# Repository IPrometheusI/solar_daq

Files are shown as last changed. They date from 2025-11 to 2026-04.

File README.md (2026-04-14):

# Sistema de Adquisición de Datos para Paneles Solares






## Resumen
Este proyecto implementa un sistema DAQ para dos paneles solares usando una Raspberry Pi 4. El sistema mide variables eléctricas y ambientales cada minuto, guarda archivos CSV diarios en la Pi y puede integrarse con InfluxDB, Grafana y Google Drive para monitoreo y respaldo.

## Sensores y Variables
- `2x INA228`: voltaje, corriente, potencia y energía de cada panel.
- `ADS1115 + Spektron 210`: irradiancia solar.
- `20x termistores NTC + 3x CD74HC4051`: temperatura en múltiples puntos del sistema.
- `DHT22`: temperatura y humedad ambiente.
- `Anemómetro`: velocidad del viento.
- `Veleta resistiva`: dirección del viento.
- `Pluviómetro`: precipitación acumulada.

## Flujo del Sistema
- Adquisición automática en horario operativo.
- Escritura de CSV diarios en `/home/pi/Desktop/Mediciones/`.
- Monitoreo local desde terminal y panel de control.
- Integración opcional con InfluxDB/Grafana y sincronización con Google Drive.

## Vista del Proyecto
| Hardware | Terminal de adquisición |
| --- | --- |
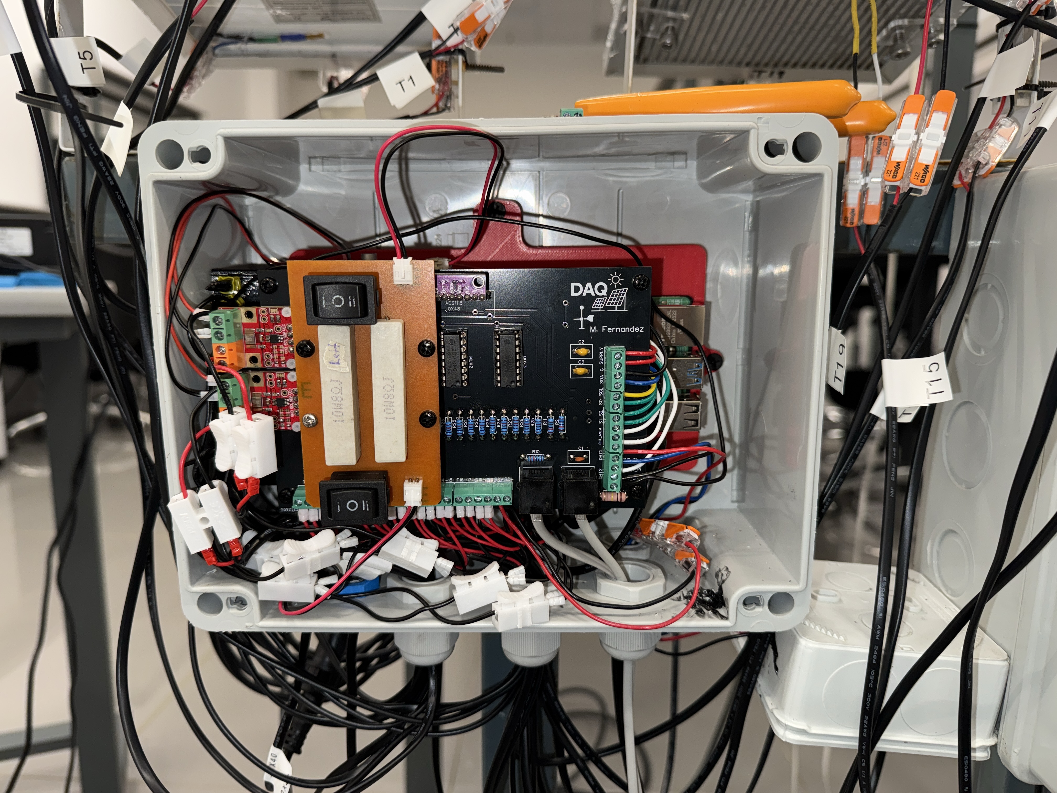
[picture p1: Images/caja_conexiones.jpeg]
Caja de conexiones del sistema
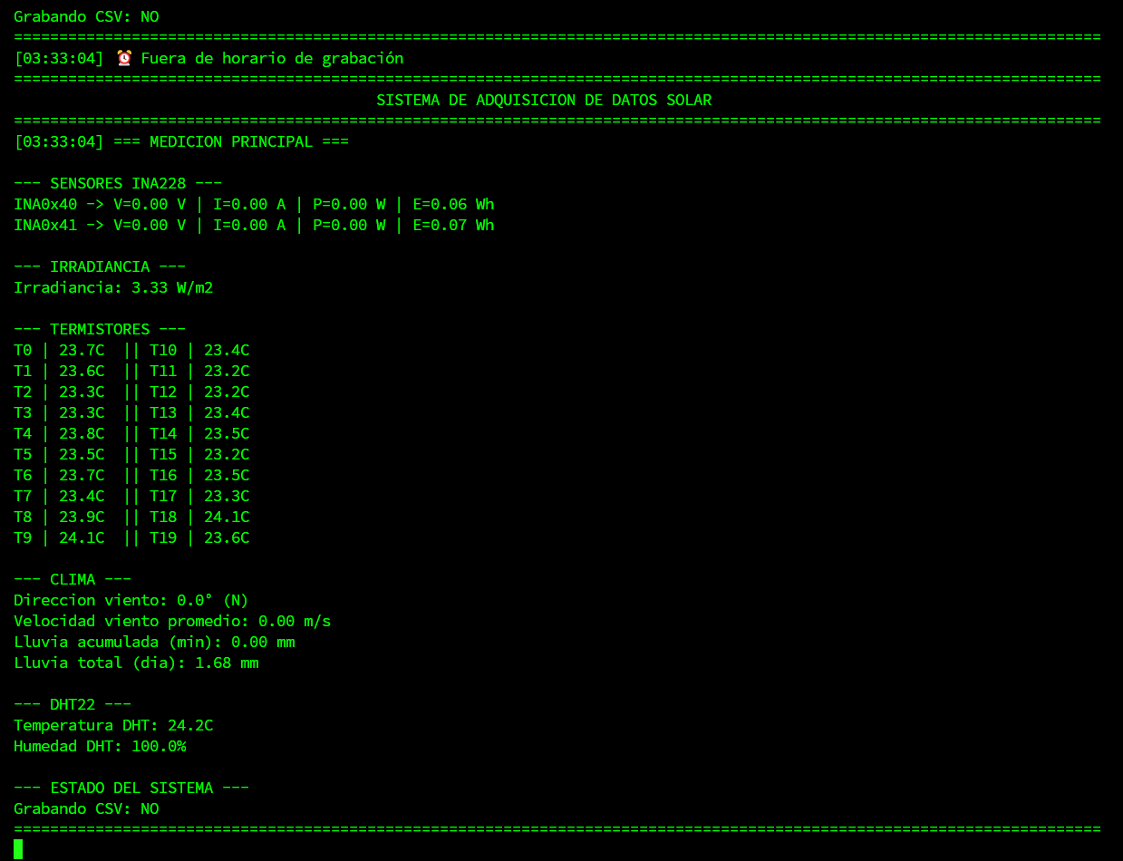
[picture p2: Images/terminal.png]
Salida en terminal del sistema DAQ
|  |  |

| Panel de control | Dashboard Grafana |
| --- | --- |
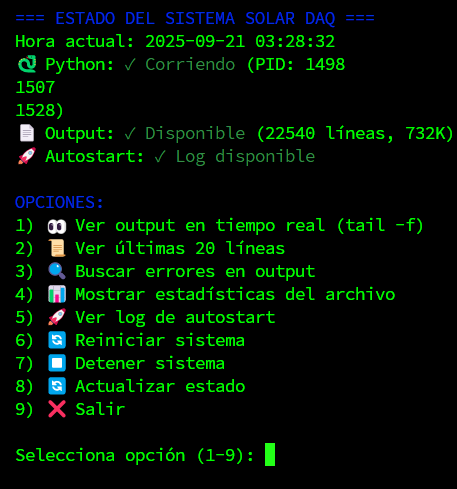
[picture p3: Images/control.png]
Panel de control en terminal
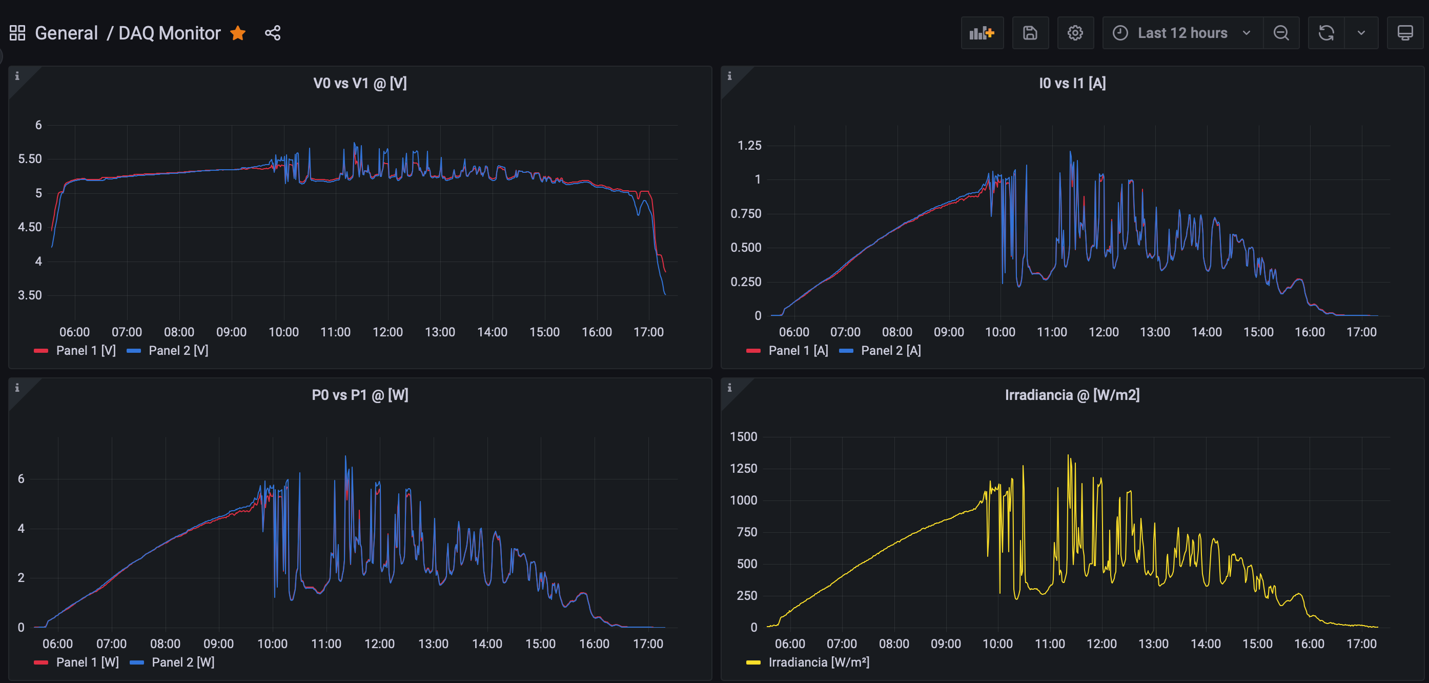
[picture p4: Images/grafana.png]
Dashboard en Grafana
|  |  |

### Respaldo en la nube
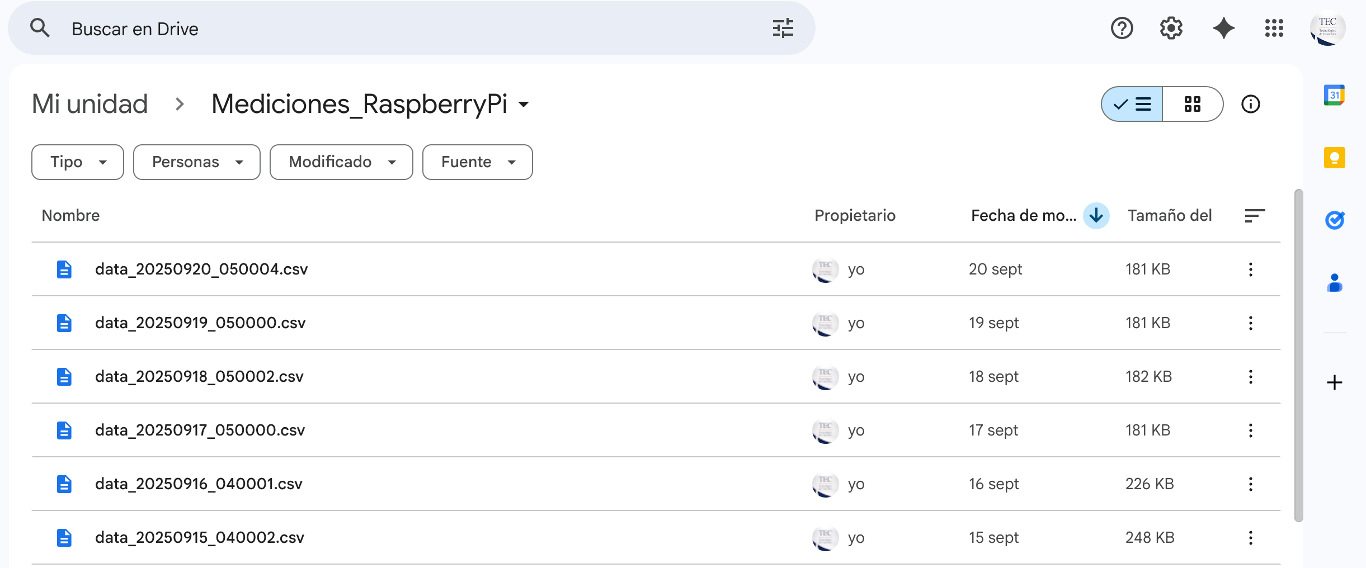
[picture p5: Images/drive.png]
Archivos CSV sincronizados en Google Drive


## Instalación en Raspberry Pi 4
Asumiendo que el hardware ya está correctamente conectado y que la Raspberry Pi OS ya está lista:

```bash
cd /home/pi/Desktop
git clone https://github.com/IPrometheusI/solar_daq.git
cd solar_daq
sudo bash setup_repo.sh
systemctl status solar_daq.service
```

`setup_repo.sh` crea el entorno virtual `.venv`, instala `requirements.txt`, copia los scripts de `bashScripts/` a `/home/pi/` y registra el servicio `solar_daq.service` para arranque automático.

Si vas a usar InfluxDB, usa [`.env.example`](.env.example) como plantilla:

```bash
cp .env.example .env
nano .env
```

Completa `INFLUX_URL`, `INFLUX_TOKEN`, `INFLUX_ORG` e `INFLUX_BUCKET`, y luego usa esos valores en el entorno donde correrá el servicio. No subas `.env` al repositorio.

## Operación Rápida
```bash
sudo systemctl start solar_daq.service
sudo systemctl stop solar_daq.service
/home/pi/control_solar_daq.sh
tail -f /home/pi/solar_daq.log
```

## Cómo Citar
Si utilizas este software en tu investigación o proyecto, usa el DOI:

`10.5281/zenodo.19562081`

También puedes usar el archivo `CITATION.cff` incluido en el repositorio.

## Licencia
Este proyecto está licenciado bajo la **Licencia MIT**. Consulta [LICENSE](LICENSE) para más detalles.

Copyright (c) 2025 Maickol A. Fernandez Obando

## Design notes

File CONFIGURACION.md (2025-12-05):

# Configuración del Sistema

Este documento explica cómo configurar las credenciales de InfluxDB para el sistema de adquisición de datos solar.

## ⚠️ Importante - Seguridad

**NUNCA** subas archivos con credenciales reales a repositorios públicos. Las credenciales deben configurarse mediante variables de entorno o archivos `.env` locales.

---

## Método 1: Variables de entorno (Recomendado para producción)

### En Linux/macOS (Raspberry Pi)

1. **Edita el archivo de perfil de tu shell:**

   ```bash
   nano ~/.bashrc
   # o si usas zsh:
   nano ~/.zshrc
   ```

2. **Agrega al final del archivo:**

   ```bash
   # InfluxDB Configuration
   export INFLUX_URL="http://tu-servidor-influxdb.com"
   export INFLUX_TOKEN="tu-token-de-influxdb-aqui"
   export INFLUX_ORG="tu-organizacion"
   export INFLUX_BUCKET="tu-bucket"
   ```

3. **Recarga el archivo de configuración:**

   ```bash
   source ~/.bashrc
   # o si usas zsh:
   source ~/.zshrc
   ```

4. **Verifica que las variables estén configuradas:**

   ```bash
   echo $INFLUX_URL
   echo $INFLUX_TOKEN
   ```

### En Windows (PowerShell)

1. **Configura las variables de entorno del sistema:**

   ```powershell
   [System.Environment]::SetEnvironmentVariable('INFLUX_URL', 'http://tu-servidor-influxdb.com', 'User')
   [System.Environment]::SetEnvironmentVariable('INFLUX_TOKEN', 'tu-token-de-influxdb-aqui', 'User')
   [System.Environment]::SetEnvironmentVariable('INFLUX_ORG', 'tu-organizacion', 'User')
   [System.Environment]::SetEnvironmentVariable('INFLUX_BUCKET', 'tu-bucket', 'User')
   ```

2. **Reinicia PowerShell** para que las variables tomen efecto.

---

## Método 2: Archivo .env (Para desarrollo local)

1. **Copia el archivo de ejemplo:**

   ```bash
   cp .env.example .env
   ```

2. **Edita el archivo `.env` con tus credenciales:**

   ```bash
   nano .env
   ```

   ```env
   # InfluxDB Configuration
   INFLUX_URL=http://tu-servidor-influxdb.com
   INFLUX_TOKEN=tu-token-de-influxdb-aqui
   INFLUX_ORG=tu-organizacion
   INFLUX_BUCKET=tu-bucket
   ```

3. **Instala python-dotenv (si no está instalado):**

   ```bash
   pip install python-dotenv
   ```

4. **Modifica los scripts para cargar el archivo `.env`** (solo necesario si usas este método):

   Al inicio de cada script Python, agrega:

   ```python
   from dotenv import load_dotenv
   load_dotenv()  # Carga variables de .env
   ```

**Nota**: El archivo `.env` ya está en `.gitignore` y NO será subido al repositorio.

---

## Método 3: Editar directamente en el código (NO recomendado)

Solo para pruebas locales. **NO subir al repositorio con credenciales reales.**

Edita los valores directos en los archivos:

- `source/influxdb_sender.py`
- `InfluxService/delete_influx_range.py`
- `InfluxService/upload_csv_to_influx.py`

```python
INFLUX_CONFIG = {
    "url": "http://tu-servidor-influxdb.com",
    "token": "tu-token-de-influxdb-aqui",
    "org": "tu-organizacion",
    "bucket": "tu-bucket",
}
```

---

## Cómo obtener las credenciales de InfluxDB

### 1. URL del servidor

Es la dirección donde está alojado tu servidor InfluxDB.

**Ejemplo**: `http://influx.ejemplo.com` o `http://192.168.1.100:8086`

### 2. Token de acceso

1. Accede a la interfaz web de InfluxDB
2. Ve a **Data** → **API Tokens** (o **Load Data** → **Tokens**)
3. Copia un token existente o crea uno nuevo con los permisos necesarios:
   - **Read** access al bucket (para queries)
   - **Write** access al bucket (para escribir datos)
   - **Delete** access al bucket (para eliminar datos)

### 3. Organización (Org)

El nombre de tu organización en InfluxDB.

Puedes verlo en la interfaz web, generalmente en la esquina superior izquierda.

### 4. Bucket

El nombre del bucket (base de datos) donde se almacenan los datos.

Puedes verlo en **Data** → **Buckets** en la interfaz web de InfluxDB.

---

## Verificar la configuración

### Para el sistema principal (implementacion.py)

1. **Ejecuta el sistema:**

   ```bash
   cd source
   python implementacion.py
   ```

2. **Verifica el log de inicio**. Deberías ver:

   ```
   ✓ Conexión a InfluxDB establecida
   ```

   Si ves errores de conexión, verifica tus credenciales.

### Para los scripts de InfluxService

1. **Prueba la conexión:**

   ```bash
   cd InfluxService
   python upload_csv_to_influx.py
   ```

2. **Deberías ver:**

   ```
   Conectando a InfluxDB: http://tu-servidor...
   ✓ Conectado a InfluxDB
   ```

---

## Troubleshooting

### Error: "INFLUX_TOKEN environment variable not set"

**Solución**: Asegúrate de haber configurado las variables de entorno correctamente.

Verifica con:
```bash
echo $INFLUX_TOKEN
```

### Error: "Connection refused" o "Timeout"

**Posibles causas**:
- URL incorrecta
- Servidor InfluxDB no está corriendo
- Firewall bloqueando la conexión
- Problemas de red

**Solución**: Verifica la conectividad:
```bash
ping tu-servidor-influxdb.com
curl http://tu-servidor-influxdb.com/health
```

### Error: "Unauthorized" o "Invalid token"

**Posibles causas**:
- Token incorrecto
- Token expirado
- Permisos insuficientes

**Solución**: Verifica/regenera el token en la interfaz web de InfluxDB.

### Error: "Bucket not found"

**Posibles causas**:
- Nombre del bucket incorrecto
- Bucket no existe en la organización especificada

**Solución**: Verifica el nombre del bucket en InfluxDB UI.

---

## Configuración para inicio automático (Raspberry Pi)

Si quieres que el sistema inicie automáticamente con las variables de entorno:

### Usando systemd (Recomendado)

1. **Crea un archivo de servicio:**

   ```bash
   sudo nano /etc/systemd/system/solar-daq.service
   ```

2. **Contenido del archivo:**

   ```ini
   [Unit]
   Description=Solar DAQ System
   After=network.target

   [Service]
   Type=simple
   User=pi
   WorkingDirectory=/home/pi/solar_daq/source
   Environment="INFLUX_URL=http://tu-servidor-influxdb.com"
   Environment="INFLUX_TOKEN=tu-token-aqui"
   Environment="INFLUX_ORG=tu-organizacion"
   Environment="INFLUX_BUCKET=tu-bucket"
   ExecStart=/usr/bin/python3 /home/pi/solar_daq/source/implementacion.py
   Restart=always
   RestartSec=10

   [Install]
   WantedBy=multi-user.target
   ```

3. **Habilita e inicia el servicio:**

   ```bash
   sudo systemctl daemon-reload
   sudo systemctl enable solar-daq.service
   sudo systemctl start solar-daq.service
   ```

4. **Verifica el estado:**

   ```bash
   sudo systemctl status solar-daq.service
   ```

---

## Archivos que contienen configuración de InfluxDB

Los siguientes archivos necesitan las credenciales configuradas:

1. ✅ `source/influxdb_sender.py` - Sistema principal de envío en tiempo real
2. ✅ `InfluxService/upload_csv_to_influx.py` - Subir datos históricos
3. ✅ `InfluxService/delete_influx_range.py` - Eliminar datos

Todos usan las mismas variables de entorno, por lo que solo necesitas configurarlas una vez.

---

## Seguridad - Lista de verificación

- [ ] Las credenciales están en variables de entorno o archivo `.env`
- [ ] El archivo `.env` NO está en el repositorio git
- [ ] El archivo `.env` está en `.gitignore`
- [ ] No hay tokens hardcodeados en archivos Python
- [ ] Los tokens tienen solo los permisos necesarios
- [ ] Las credenciales se guardan de forma segura (no en texto plano en lugares públicos)

---

**Última actualización**: 2025-12-04

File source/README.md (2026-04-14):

# source

Esta carpeta contiene el runtime principal del sistema DAQ. Aqui vive el proceso que `setup_repo.sh` instala y que `start_solar_daq.sh` ejecuta mediante `systemd`.

## Archivos

- `implementacion.py`: bucle principal de adquisicion. Lee INA228, ADS1115, DHT22, anemometro, pluviometro e irradiancia; guarda CSV diarios y recupera estado despues de reinicios.
- `influxdb_sender.py`: integracion opcional con InfluxDB. Inicializa la conexion, genera puntos y reintenta si la conexion falla.

## Flujo operativo

1. `bashScripts/start_solar_daq.sh` activa `.venv`.
2. Ejecuta `source/implementacion.py`.
3. El sistema escribe CSV en `/home/pi/Desktop/Mediciones`.
4. El estado de recuperacion se guarda en `/home/pi/Desktop/sensor_system_state.json` y `/home/pi/Desktop/sensor_system_state_backup.json`.

## Configuracion relevante

- Horario operativo actual: `05:00` a `18:00`.
- Direcciones INA228 esperadas: `0x40` y `0x41`.
- ADS1115 esperado en `0x48`.
- InfluxDB usa `INFLUX_URL`, `INFLUX_TOKEN`, `INFLUX_ORG` e `INFLUX_BUCKET`.

## Ejecucion manual

```bash
source .venv/bin/activate
python source/implementacion.py
```

En Raspberry Pi, `pigpiod` debe estar activo antes de iniciar el sistema:

```bash
sudo systemctl enable --now pigpiod
```

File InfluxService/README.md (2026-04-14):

# InfluxService

Herramientas de utilidad para gestionar datos en InfluxDB del sistema de adquisición de datos solar.

## Descripción

Esta carpeta contiene scripts de Python para realizar operaciones de mantenimiento y recuperación de datos en la base de datos InfluxDB:

- **Subir datos históricos desde archivos CSV**
- **Eliminar datos en rangos de tiempo específicos**

Ambos scripts están diseñados para trabajar con la zona horaria de Costa Rica (`America/Costa_Rica`) y convertir automáticamente a UTC para InfluxDB.

---

## Archivos

### 1. `upload_csv_to_influx.py`

**Propósito**: Subir datos históricos desde archivos CSV a InfluxDB con filtrado por rango de tiempo.

**Uso típico**:
- Recuperar datos perdidos por problemas de conectividad
- Migrar datos históricos a InfluxDB
- Re-subir datos específicos de ciertos períodos

#### Características

- ✅ Lectura automática de archivos CSV desde `archivos_csv/`
- ✅ Filtrado por rango de tiempo (hora inicio - hora fin)
- ✅ Conversión automática de timezone CR → UTC
- ✅ Manejo de BOM UTF-8
- ✅ Mapeo completo de todos los campos del CSV a InfluxDB
- ✅ Validación de datos antes de subir
- ✅ Contador de puntos subidos y omitidos

#### Formato de archivos CSV esperado

```
data_YYYYMMDD_HHMMSS.csv
```

Ejemplo: `data_20251018_083000.csv`

#### Estructura del CSV

El CSV debe contener las siguientes columnas:

**Columnas principales:**
- `V0[V]`, `V1[V]` - Voltaje paneles 1 y 2
- `I0[A]`, `I1[A]` - Corriente paneles 1 y 2
- `P0[W]`, `P1[W]` - Potencia paneles 1 y 2
- `E0[Wh]`, `E1[Wh]` - Energía acumulada paneles 1 y 2
- `Irr[W/m2]` - Irradiancia
- `Rain[mm]` - Lluvia acumulada
- `Wind_Speed[m/s]` - Velocidad del viento
- `Wind_Direction` - Dirección del viento (formato: `90.0°(E)`)
- `DHT_HUM[%]` - Humedad ambiente
- `DHT_TEMP[°C]` - Temperatura ambiente

**Termistores:**
- `T0[°C]` a `T19[°C]` - 20 sensores de temperatura

**Timestamp:**
- `DateTime` - Formato: `YYYY-MM-DD HH:MM:SS` (hora local CR)

#### Mapeo a InfluxDB

| Columna CSV | Field InfluxDB | Tipo |
|---|---|---|
| V0[V] | panel1_voltage | float |
| V1[V] | panel2_voltage | float |
| I0[A] | panel1_current | float |
| I1[A] | panel2_current | float |
| P0[W] | panel1_power | float |
| P1[W] | panel2_power | float |
| E0[Wh] | panel1_energy | float |
| E1[Wh] | panel2_energy | float |
| Irr[W/m2] | irradiance | float |
| Rain[mm] | rain_accumulation | float |
| Wind_Speed[m/s] | wind_speed | float |
| Wind_Direction | wind_direction | float (solo grados) |
| DHT_HUM[%] | ambient_humidity | float |
| DHT_TEMP[°C] | ambient_temperature | float |
| T0[°C] - T19[°C] | thermistor_00_temp - thermistor_19_temp | float |

**Tags adicionales:**
- `system`: `raspberry_pi`
- `location`: `solar_farm`

**Measurement**: `solar_panel_measurement`

#### Cómo usar

1. **Asegúrate de tener archivos CSV en la carpeta `archivos_csv/`**

2. **Ejecuta el script:**
   ```bash
   python upload_csv_to_influx.py
   ```

3. **Sigue las instrucciones interactivas:**
   ```
   === CSV to InfluxDB Uploader ===

   Archivos CSV disponibles:
     1. data_20251018_083000.csv - 2025-10-18 08:30:00
     2. data_20251019_083000.csv - 2025-10-19 08:30:00

   Seleccione el archivo CSV (1-2): 1

   Archivo seleccionado: data_20251018_083000.csv
   Fecha del archivo: 2025-10-18

   Ingrese el rango de tiempo para subir datos:
   Formato: HH:MM (ejemplo: 08:30)

   Hora inicio (HH:MM): 08:30
   Hora fin (HH:MM): 17:45

   Rango seleccionado: 08:30 - 17:45

   ¿Confirmar subida de datos a InfluxDB? (si/no): si
   ```

4. **El script mostrará el progreso:**
   ```
   Conectando a InfluxDB: http://tu-servidor-influxdb.com...
   ✓ Conectado a InfluxDB

   ✓ Uploaded 558 points from data_20251018_083000.csv
     Skipped 0 points outside time range

   === Resumen ===
   Archivo procesado: data_20251018_083000.csv
   Rango de tiempo: 08:30 - 17:45
   Puntos totales subidos: 558
   ✓ Carga completada exitosamente
   ```

#### Casos especiales

**Rangos que cruzan medianoche:**

El script maneja correctamente rangos de tiempo que cruzan la medianoche:

```
Hora inicio (HH:MM): 23:00
Hora fin (HH:MM): 02:00
```

Esto subirá datos desde las 23:00 hasta las 02:00 del día siguiente.

**Valores N/A o inválidos:**

El script omite automáticamente valores que son:
- Vacíos
- "N/A"
- NaN
- No numéricos

---

### 2. `delete_influx_range.py`

**Propósito**: Eliminar datos de InfluxDB en un rango de tiempo específico.

**Uso típico**:
- Eliminar datos corruptos o erróneos
- Limpiar datos de pruebas
- Corregir datos duplicados

#### Características

- ✅ Conversión automática de hora local CR a UTC
- ✅ Previsualización de puntos a eliminar antes de confirmar
- ✅ Confirmación explícita requerida (escribir "DELETE")
- ✅ Validación de formato de fecha y hora
- ✅ Soporte para filtrado por tags (opcional)

#### Cómo usar

1. **Ejecuta el script:**
   ```bash
   python delete_influx_range.py
   ```

2. **Sigue las instrucciones interactivas:**
   ```
   === Delete InfluxDB Data ===

   Ingrese los datos para eliminar:

   Fecha (YYYY-MM-DD, ejemplo: 2025-10-18): 2025-10-18
   Hora inicio (HH:MM, ejemplo: 08:30): 08:30
   Hora fin (HH:MM, ejemplo: 17:45): 17:45

   === Plan de Eliminación ===
    URL        : http://tu-servidor-influxdb.com
    Org        : tu-organizacion
    Bucket     : tu-bucket
    Measurement: solar_panel_measurement
    Tags       : (none)
    Local CR   : 2025-10-18 08:30 -> 17:45
    UTC Window : 2025-10-18T14:30:00Z -> 2025-10-18T23:45:00Z  (stop is exclusive)
    Predicate  : _measurement="solar_panel_measurement"
   ============================

   Puntos encontrados que coinciden: 558

   ¿Confirmar eliminación de estos datos? Escriba 'DELETE' para confirmar: DELETE

   ✅ Solicitud de eliminación completada exitosamente.
   ```

#### ⚠️ Advertencias importantes

1. **La eliminación es IRREVERSIBLE** - Los datos no se pueden recuperar después de eliminar
2. **Debes escribir exactamente "DELETE"** en mayúsculas para confirmar
3. **El tiempo de fin (stop) es EXCLUSIVO** - Los datos en ese momento exacto NO se eliminan
4. **Verifica siempre el preview** antes de confirmar

#### Funcionamiento técnico

El script utiliza la **InfluxDB Delete API** que tiene las siguientes limitaciones:

- ✅ Puede filtrar por `_measurement`
- ✅ Puede filtrar por tags
- ❌ **NO puede filtrar por fields** (_field)

Esto significa que eliminará **todos los fields** que coincidan con el measurement y tags en el rango de tiempo especificado.

---

## Requisitos

### Dependencias Python

Ambos scripts requieren las siguientes dependencias:

```bash
pip install influxdb-client
```

Para Python < 3.9, también necesitas:

```bash
pip install backports.zoneinfo
```

### Python versión

- **Recomendado**: Python 3.9 o superior (soporte nativo de zoneinfo)
- **Mínimo**: Python 3.7 (requiere backports.zoneinfo)

### Configuración de InfluxDB

Los scripts usan la siguiente configuración (definida en ambos archivos):

```python
INFLUX_CONFIG = {
    "url": "http://tu-servidor-influxdb.com",
    "token": "tu-token-de-influxdb-aqui",
    "org": "tu-organizacion",
    "bucket": "tu-bucket",
}
```

**Nota de seguridad**: En producción, considera mover el token a variables de entorno:

```python
import os
INFLUX_CONFIG = {
    "token": os.getenv("INFLUX_TOKEN"),
    # ...
}
```

---

## Zona Horaria

**Importante**: Ambos scripts trabajan con la zona horaria de **Costa Rica** (`America/Costa_Rica`).

- **Entrada del usuario**: Hora local de Costa Rica
- **Conversión automática**: Los scripts convierten a UTC para InfluxDB
- **UTC offset**: Costa Rica = UTC-6 (sin cambio de horario de verano)

### Ejemplo de conversión:

```
Local CR: 2025-10-18 08:30
UTC:      2025-10-18 14:30
```

---

## Estructura de directorios esperada

```
solar_daq/
├── InfluxService/
│   ├── README.md                    # Este archivo
│   ├── upload_csv_to_influx.py     # Subir CSVs
│   └── delete_influx_range.py      # Eliminar datos
├── archivos_csv/                    # Carpeta de CSVs (para upload)
│   ├── data_20251018_083000.csv
│   ├── data_20251019_083000.csv
│   └── ...
└── source/
    ├── implementacion.py            # Sistema principal
    └── influxdb_sender.py          # Envío en tiempo real
```

---

## Flujo de trabajo común

### Escenario 1: Recuperar datos perdidos

1. **Identifica el período sin datos** en InfluxDB
2. **Localiza el archivo CSV correspondiente** en `archivos_csv/`
3. **Ejecuta `upload_csv_to_influx.py`**
4. **Selecciona el archivo y rango de tiempo**
5. **Confirma la subida**

### Escenario 2: Corregir datos erróneos

1. **Identifica el rango de datos incorrectos**
2. **Ejecuta `delete_influx_range.py`**
3. **Especifica fecha y rango de tiempo**
4. **Verifica el preview de puntos a eliminar**
5. **Confirma con "DELETE"**
6. **Re-sube los datos correctos** con `upload_csv_to_influx.py`

### Escenario 3: Datos duplicados

1. **Identifica el rango duplicado**
2. **Ejecuta `delete_influx_range.py`** para eliminar todos los datos del rango
3. **Ejecuta `upload_csv_to_influx.py`** para re-subir los datos correctos una sola vez

---

## Troubleshooting

### Error: "Module 'zoneinfo' not found"

**Solución**:
```bash
pip install backports.zoneinfo
```

### Error: "Module 'influxdb_client' not found"

**Solución**:
```bash
pip install influxdb-client
```

### Error: "Folder 'archivos_csv' does not exist"

**Solución**: Crea la carpeta o ajusta la ruta en el script:
```bash
mkdir archivos_csv
```

O modifica la constante:
```python
CSV_FOLDER = "ruta/a/tus/csvs"
```

### InfluxDB health check failed

**Posibles causas**:
- Servidor InfluxDB no disponible
- Token inválido o expirado
- Problemas de red/firewall

**Solución**:
```bash
# Verifica conectividad
ping tu-servidor-influxdb.com

# Verifica el servidor InfluxDB está corriendo
curl http://tu-servidor-influxdb.com/health
```

### Puntos encontrados: 0 (pero debería haber datos)

**Posibles causas**:
- Rango de tiempo incorrecto
- Measurement name diferente
- Datos ya fueron eliminados

**Solución**: Verifica con una query Flux en InfluxDB UI:
```flux
from(bucket: "tu-bucket")
  |> range(start: -7d)
  |> filter(fn: (r) => r._measurement == "solar_panel_measurement")
  |> limit(n: 10)
```

---

## Advertencias de seguridad

⚠️ **Token de acceso**: Los scripts contienen el token de InfluxDB en texto plano. En producción:
- Usa variables de entorno
- Restringe permisos del archivo
- No subas el token a repositorios públicos

⚠️ **Permisos del token**: Asegúrate de que el token tiene:
- Permiso de **escritura** (write) para `upload_csv_to_influx.py`
- Permiso de **eliminación** (delete) para `delete_influx_range.py`
- Permiso de **lectura** (read) para preview queries

---

## Funciones documentadas

Cada función en los scripts está documentada siguiendo el formato:

```python
###################################
# nombre_funcion
# Argumentos:
#   - parametro1 (tipo): Descripción
#   - parametro2 (tipo): Descripción
# Return: tipo - Descripción del valor de retorno
# Descripcion: Descripción detallada de la función
###################################
```

Para más detalles, consulta directamente los archivos de código fuente.

---

## Contacto y soporte

Para problemas o preguntas sobre estos scripts, contacta al equipo de desarrollo del sistema de adquisición de datos solar.

---

**Última actualización**: 2025-12-04

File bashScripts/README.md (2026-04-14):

# bashScripts

Esta carpeta contiene los scripts auxiliares usados para arrancar, controlar y sincronizar el sistema Solar DAQ en la Raspberry Pi.

## Flujo actual
El arranque principal del sistema se hace con `start_solar_daq.sh`. Después de ejecutar `setup_repo.sh`, los scripts de esta carpeta se copian a `/home/pi/` y el servicio `solar_daq.service` usa `/home/pi/start_solar_daq.sh` para iniciar el software automáticamente al encender o reiniciar la Pi.

## Scripts

### `start_solar_daq.sh`
Lanzador principal del sistema.

- Resuelve la ruta real del repositorio.
- Activa el entorno virtual.
- Entra a `source/`.
- Ejecuta `implementacion.py`.
- Escribe eventos en `/home/pi/solar_daq.log`.

Uso manual:

```bash
/home/pi/start_solar_daq.sh
```

### `control_solar_daq.sh`
Panel de control en terminal, pensado para uso remoto por SSH o desde consola local.

Permite:
- ver `tail -f` del log
- revisar últimas líneas y errores
- iniciar, reiniciar o detener el sistema
- consultar estado general

Uso:

```bash
/home/pi/control_solar_daq.sh
```

### `sync_mediciones.sh`
Sincroniza los CSV de `/home/pi/Desktop/Mediciones` hacia Google Drive usando `rclone`.

Asume este remoto:

```bash
gdrive:Mediciones_RaspberryPi
```

Uso:

```bash
/home/pi/sync_mediciones.sh
```

Si quieres automatizar la sincronización, agrega una tarea en `crontab`:

```bash
crontab -e
```

Ejemplo, cada 5 minutos:

```cron
*/5 * * * * /home/pi/sync_mediciones.sh
```

### `resolve_project_root.sh`
Helper interno para encontrar la ruta real del repositorio aunque los scripts hayan sido copiados a `/home/pi`. No está pensado para ejecutarse directamente.

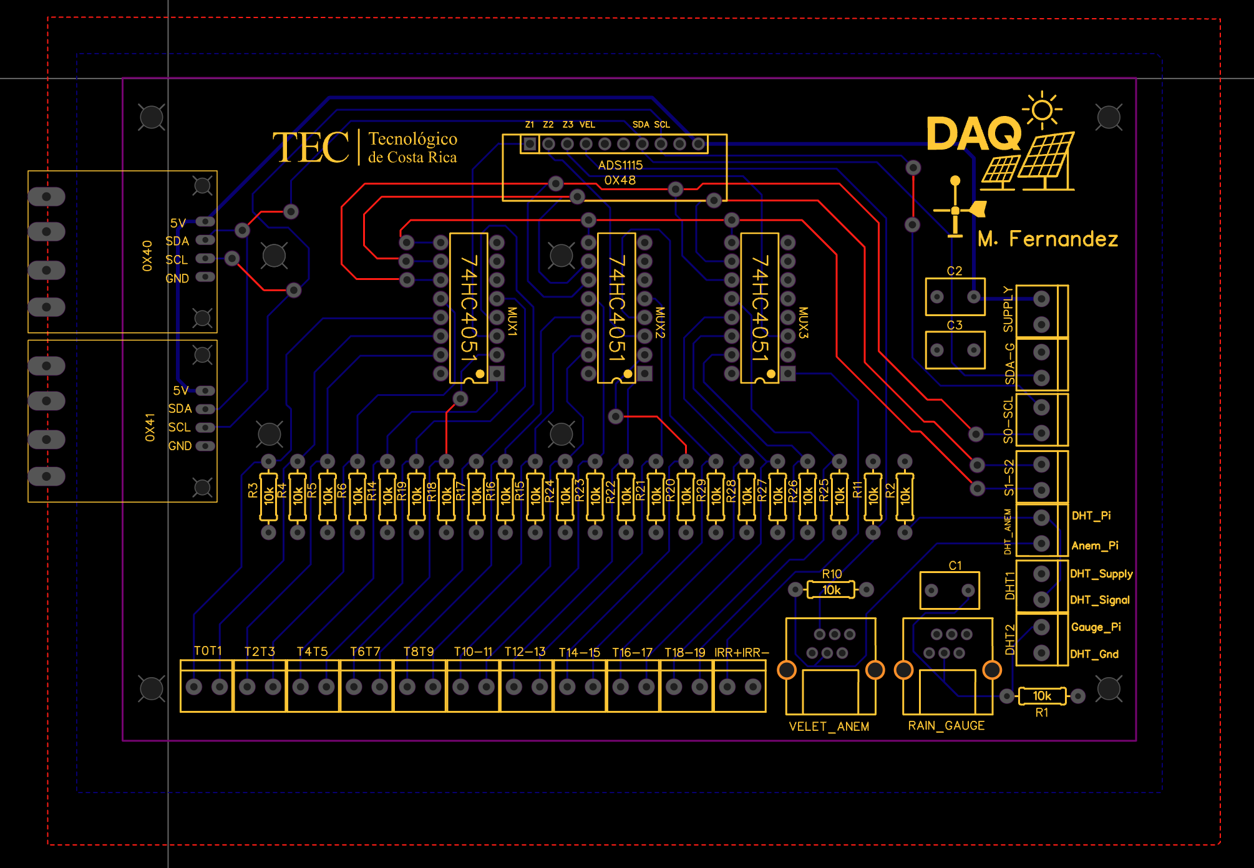
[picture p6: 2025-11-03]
Documentacion/Esquematicos/pcb_daq.png

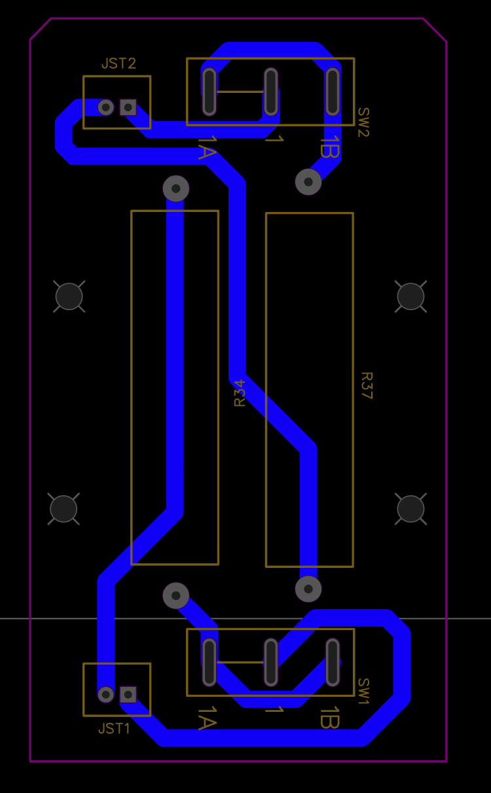
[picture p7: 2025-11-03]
Documentacion/Esquematicos/pcb_resistencias.png

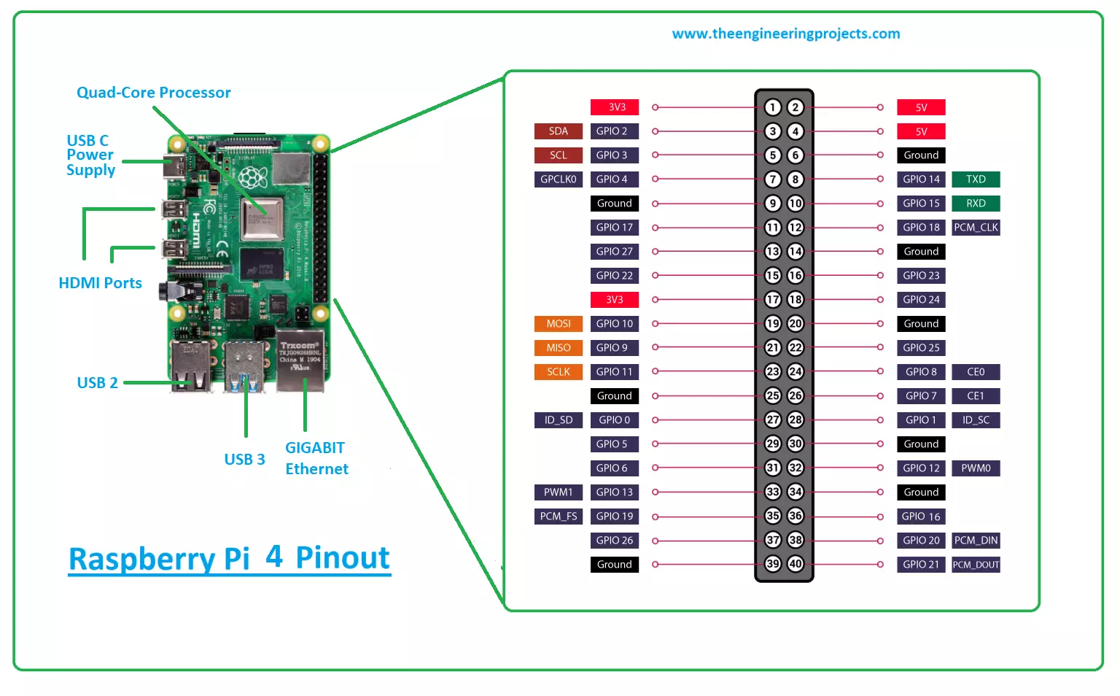
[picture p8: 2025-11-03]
Documentacion/raspberry-pi-4.png

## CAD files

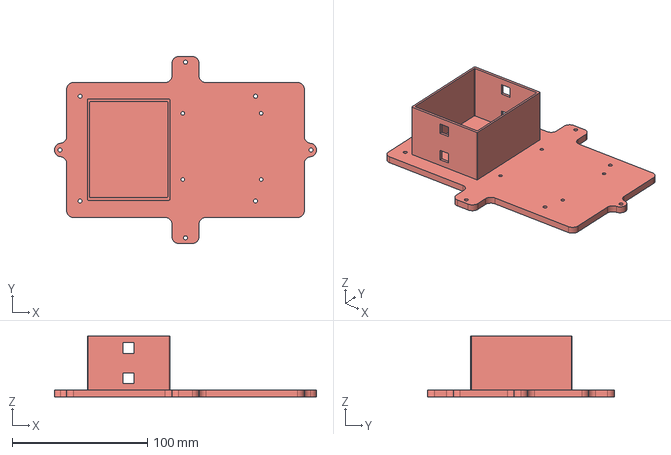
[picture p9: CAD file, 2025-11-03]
Documentacion/Diseno3D/Ensamble_PCB v6.step
194.0 x 138.4 x 45.0 mm

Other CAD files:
Documentacion/Diseno3D/DAQ+System v1.f3d

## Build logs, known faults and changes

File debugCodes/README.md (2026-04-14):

# debugCodes

Esta carpeta agrupa scripts de diagnostico rapido para probar sensores por separado antes de correr el DAQ completo. Estan pensados para ejecutarse directamente en la Raspberry Pi, con el hardware ya conectado.

## Antes de usarlos

```bash
source .venv/bin/activate
sudo systemctl enable --now pigpiod
```

`pigpiod` es importante para los scripts que usan `gpiozero`.

## Scripts disponibles

- `ina228_monitor.py`: monitor en tiempo real para los dos INA228 (`0x40` y `0x41`). Muestra voltaje, corriente, potencia, energia y temperatura interna.
- `thermistor_monitor.py`: verifica `T0` a `T19` y tambien muestra DHT22. Usa el ADS1115 y el multiplexor.
- `irradiance_monitor.py`: prueba solo el canal de irradiancia y reporta mV y `W/m2`.
- `weather_kit_monitor.py`: integra viento, lluvia, direccion, DHT22 e irradiancia en una sola vista de diagnostico.
- `gauge.py`: solucionador interactivo para el pluviometro. Permite probar `RPi.GPIO`, `gpiozero` o polling manual.
- `test_influxdb.py`: envia datos simulados a InfluxDB usando `source/influxdb_sender.py`.

## Comandos utiles

```bash
python debugCodes/ina228_monitor.py
python debugCodes/thermistor_monitor.py
python debugCodes/irradiance_monitor.py
python debugCodes/weather_kit_monitor.py
python debugCodes/gauge.py
python debugCodes/test_influxdb.py
```

Para `test_influxdb.py`, primero define las variables de `.env.example`:

```bash
cp .env.example .env
set -a
source .env
set +a
python debugCodes/test_influxdb.py
```

Si un script falla, revisa primero `i2cdetect -y 1`, el estado de `pigpiod` y que no haya otro proceso ocupando los GPIO.

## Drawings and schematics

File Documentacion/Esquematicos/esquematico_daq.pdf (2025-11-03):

A | A

1

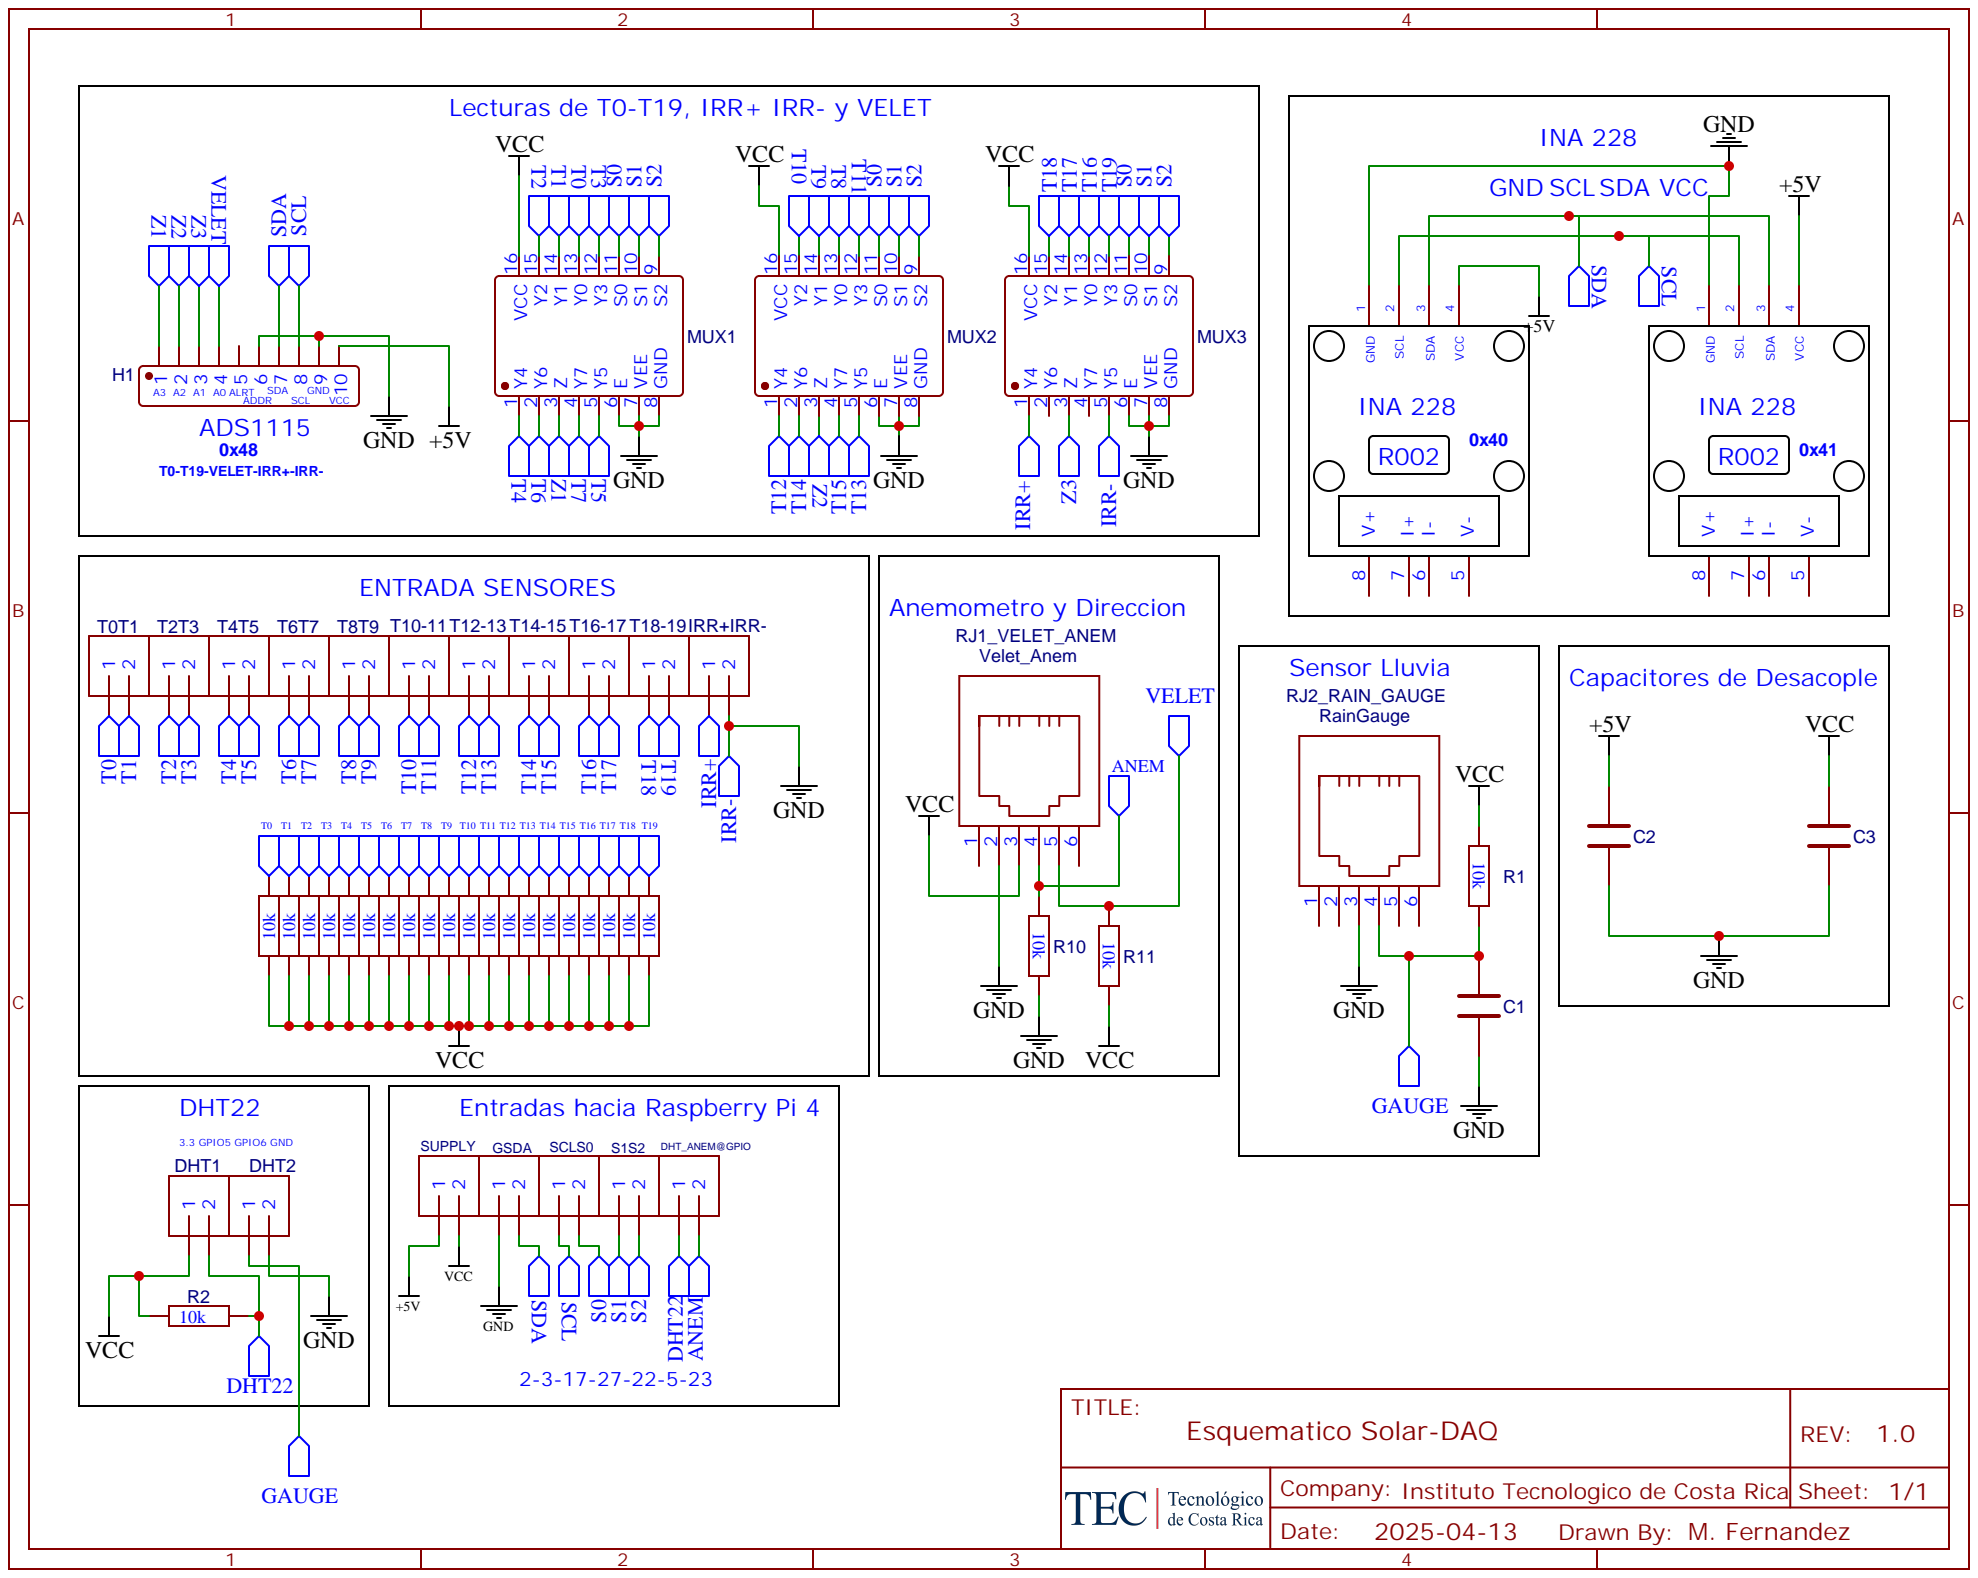
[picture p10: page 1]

VCC
Entradas hacia Raspberry Pi 4

Company: Instituto Tecnologico de Costa Rica

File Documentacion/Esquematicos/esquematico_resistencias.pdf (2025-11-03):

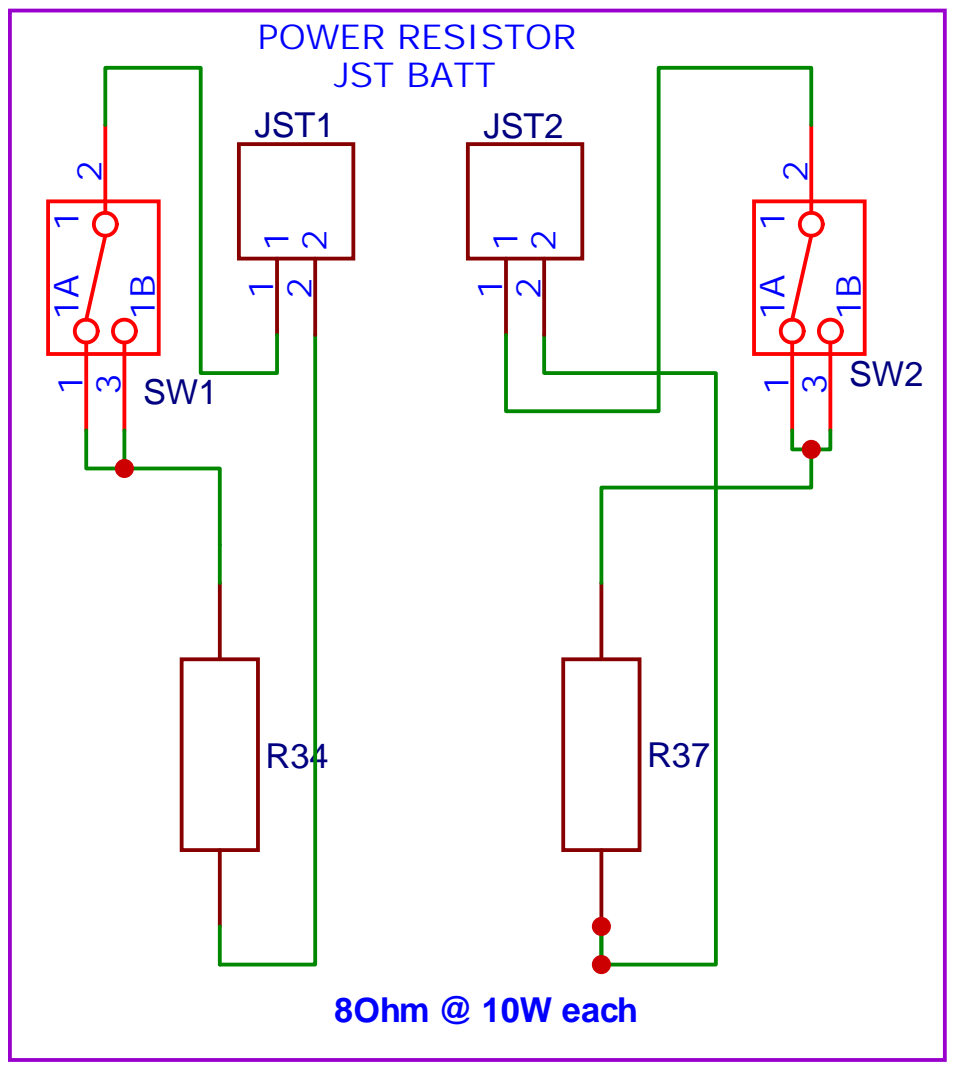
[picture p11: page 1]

Company: Instituto Tecnologico de Costa Rica

Drawn By: Team Taller

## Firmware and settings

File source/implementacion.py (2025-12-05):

#!/usr/bin/env python3
# -*- coding: utf-8 -*-

import csv
import glob
import json
import math
import os
import signal
import sys
import threading
import time
from collections import deque
from contextlib import contextmanager
from datetime import datetime

import adafruit_ads1x15.ads1115 as ADS
import adafruit_dht
import board
import busio
import RPi.GPIO as GPIO
from adafruit_ads1x15.analog_in import AnalogIn
from adafruit_ina228 import INA228
from gpiozero import Button, Device
from gpiozero.pins.pigpio import PiGPIOFactory

hardware_lock = threading.Lock()

# InfluxDB integration
try:
    from influxdb_sender import (
        close_influxdb,
        init_influxdb,
        periodic_health_check,
        send_measurement_to_influx,
    )

    INFLUX_AVAILABLE = True
except ImportError:
    print("InfluxDB módulo no disponible - solo guardará en CSV")
    INFLUX_AVAILABLE = False

if sys.stdout.encoding != "utf-8":
    sys.stdout.reconfigure(encoding="utf-8")

Device.pin_factory = PiGPIOFactory()

# Estado y configuración
STATE_FILE = "/home/pi/Desktop/sensor_system_state.json"
BACKUP_STATE_FILE = "/home/pi/Desktop/sensor_system_state_backup.json"

# Energy offset tracking (para recuperación después de reinicios)
energy_offset = {0x40: 0.0, 0x41: 0.0}

# INA228 Configuration
RSHUNT_OHMS = 0.002
IMAX_AMPS = 1.5
INA228_ADDRESSES = [0x40, 0x41]
AVG_TARGET = 1024
CT_TARGET_US = 1052
ADC_RANGE = 1

# Constantes del sistema
OPERATING_START_TIME = "05:00"  # Formato 24h "HH:MM"
OPERATING_END_TIME = "18:00"  # Formato 24h "HH:MM" (soporta cruce de medianoche)
MAX_RETRY_ATTEMPTS = 3
SENSOR_READ_TIMEOUT = 1
GPIO_SETUP_DELAY = 0.1  # Tiempo de estabilización del MUX (0.1s para irradiancia)
HARDWARE_RETRY_DELAY = 2
MAX_CONSECUTIVE_ERRORS = 10

# GPIO Configuration
try:
    GPIO.cleanup()
except Exception:
    pass

GPIO.setmode(GPIO.BCM)
GPIO.setwarnings(False)

MUX_S0 = 17
MUX_S1 = 27
MUX_S2 = 22

DHT22_PIN = 5
ANEMOMETER_PIN = 23
RAIN_SENSOR_PIN = 6

# Sensor setup
dhtDevice = adafruit_dht.DHT22(board.D5, use_pulseio=False)

# Wind and rain
KPH_PER_COUNT_PER_SEC = 2.4
MEASUREMENT_PERIOD = 1.0
wind_count = 0
last_wind_measurement = time.time()

MM_PER_TICK = 0.2794
rain_count = 0
rain_count_total = 0
terminal_rain_count = 0

# Termistores
A = 1.12924e-3
B = 2.34108e-4
C = 8.7755e-8
R_REF = 10000

THERMISTOR_REF_RESISTANCES = {
    "T0": 10030,
    "T1": 10050,
    "T2": 10000,
    "T3": 9990,
    "T4": 10000,
    "T5": 10020,
    "T6": 10030,
    "T7": 9990,
    "T8": 10000,
    "T9": 10020,
    "T10": 9980,
    "T11": 9980,
    "T12": 9970,
    "T13": 10030,
    "T14": 10000,
    "T15": 9980,
    "T16": 10010,
    "T17": 9980,
    "T18": 10010,
    "T19": 10000,
}

DIRECTION_TABLE = {
    0.0: 33_000,
    22.5: 6_570,
    45.0: 8_200,
    67.5: 891,
    90.0: 1_000,
    112.5: 688,
    135.0: 2_200,
    157.5: 1_410,
    180.0: 3_900,
    202.5: 3_140,
    225.0: 16_000,
    247.5: 14_120,
    270.0: 120_000,
    292.5: 42_120,
    315.0: 64_900,
    337.5: 21_880,
}

COMPASS = {
    0.0: "N",
    22.5: "NNE",
    45.0: "NE",
    67.5: "ENE",
    90.0: "E",
    112.5: "ESE",
    135.0: "SE",
    157.5: "SSE",
    180.0: "S",
    202.5: "SSW",
    225.0: "SW",
    247.5: "WSW",
    270.0: "W",
    292.5: "WNW",
    315.0: "NW",
    337.5: "NNW",
}

# Data storage
dht_temps = deque(maxlen=12)
dht_hums = deque(maxlen=12)
VCC = 3.294
wind_speeds_second = deque(maxlen=60)
thermistor_readings = {f"T{i}": deque(maxlen=12) for i in range(20)}

# Control variables
data_lock = threading.Lock()
running = False
measuring_active = True
file_recording_active = False
current_csv_file = None
ads = None
adc_channels = []
ina_sensors = {}
anemometer = None
rain_sensor = None
system_start_time = None
last_watchdog = time.time()
last_file_creation_day = -1
last_measurement_minute = -1

# InfluxDB control
influx_initialized = False

###################################
# OPERATING HOURS HELPER FUNCTIONS
###################################


###################################
# is_within_operating_hours
# Argumentos: now (datetime, opcional) - Momento a verificar, por defecto datetime.now()
# Return: bool - True si estamos dentro del horario de operación, False si no
# Descripcion: Verifica si estamos dentro del horario de operación. Soporta rangos que cruzan medianoche
###################################
def is_within_operating_hours(now=None):
    """Verifica si estamos dentro del horario de operación.
    Soporta rangos que cruzan medianoche (ej: 22:00 a 06:00)
    """
    if now is None:
        now = datetime.now()

    start_hour, start_min = map(int, OPERATING_START_TIME.split(":"))
    end_hour, end_min = map(int, OPERATING_END_TIME.split(":"))

    current_minutes = now.hour * 60 + now.minute
    start_minutes = start_hour * 60 + start_min
    end_minutes = end_hour * 60 + end_min

    # Si el rango cruza medianoche
    if end_minutes <= start_minutes:
        return current_minutes >= start_minutes or current_minutes < end_minutes
    else:
        return start_minutes <= current_minutes < end_minutes


###################################
# get_operating_start_hour
# Argumentos: Ninguno
# Return: int - Hora de inicio de operación (0-23)
# Descripcion: Extrae la hora de inicio del horario de operación
###################################
def get_operating_start_hour():
    """Retorna la hora de inicio de operación (0-23)"""
    return int(OPERATING_START_TIME.split(":")[0])


###################################
# get_operating_end_hour
# Argumentos: Ninguno
# Return: int - Hora de fin de operación (0-23)
# Descripcion: Extrae la hora de fin del horario de operación
###################################
def get_operating_end_hour():
    """Retorna la hora de fin de operación (0-23)"""
    return int(OPERATING_END_TIME.split(":")[0])


###################################
# is_time_to_create_daily_file
# Argumentos: now (datetime, opcional) - Momento a verificar
# Return: bool - True si es momento de crear archivo diario
# Descripcion: Verifica si estamos al inicio del horario de operación (hora y minuto 0)
###################################
def is_time_to_create_daily_file(now=None):
    """Verifica si es momento de crear el archivo diario (inicio del horario de operación)"""
    if now is None:
        now = datetime.now()

    start_hour, start_min = map(int, OPERATING_START_TIME.split(":"))
    return now.hour == start_hour and now.minute == start_min


###################################
# is_end_of_day
# Argumentos: now (datetime, opcional) - Momento a verificar
# Return: bool - True si estamos al final del día de operación
# Descripcion: Verifica si estamos al final del horario de operación (hora y minuto 0)
###################################
def is_end_of_day(now=None):
    """Verifica si estamos al final del día de operación"""
    if now is None:
        now = datetime.now()

    end_hour, end_min = map(int, OPERATING_END_TIME.split(":"))
    return now.hour == end_hour and now.minute == end_min


###################################
# TimeoutException
# Argumentos: Ninguno
# Return: Exception class
# Descripcion: Excepción personalizada para manejo de timeouts
###################################
class TimeoutException(Exception):
    pass


###################################
# timeout
# Argumentos: duration (int) - Duración del timeout en segundos
# Return: Context manager
# Descripcion: Context manager para implementar timeout en operaciones I2C
###################################
@contextmanager
def timeout(duration):
    def timeout_handler(signum, frame):
        raise TimeoutException(f"Timeout después de {duration} segundos")

    signal.signal(signal.SIGALRM, timeout_handler)
    signal.alarm(duration)

    try:
        yield
    finally:
        signal.alarm(0)


###################################
# _try_set
# Argumentos: prop_name (str), sensor (object), preferred (any), fallback (any, opcional)
# Return: None
# Descripcion: Intenta configurar una propiedad de sensor con valor preferido y fallback
###################################
def _try_set(prop_name, sensor, preferred, fallback=None):
    if not hasattr(sensor, prop_name):
        return
    try:
        setattr(sensor, prop_name, preferred)
    except Exception:
        if fallback is not None:
            try:
                setattr(sensor, prop_name, fallback)
            except Exception:
                pass


###################################
# setup_ina228
# Argumentos: i2c (busio.I2C), address (int) - Dirección I2C del sensor
# Return: INA228 object o excepción
# Descripcion: Configura un sensor INA228 con parámetros optimizados para máxima precisión
###################################
def setup_ina228(i2c, address):
    try:
        s = INA228(i2c, address=address)
        _try_set("adc_range", s, ADC_RANGE)
        s.set_calibration(shunt_res=RSHUNT_OHMS, max_current=IMAX_AMPS)
        _try_set("averaging_count", s, AVG_TARGET, fallback=7)
        _try_set("bus_voltage_conv_time", s, CT_TARGET_US, fallback=5)
        _try_set("shunt_voltage_conv_time", s, CT_TARGET_US, fallback=5)
        _try_set("temp_conv_time", s, CT_TARGET_US, fallback=5)
        _try_set("conversion_time_bus", s, CT_TARGET_US, fallback=5)
        _try_set("conversion_time_shunt", s, CT_TARGET_US, fallback=5)
        _try_set("conversion_time_temperature", s, CT_TARGET_US, fallback=5)

        if hasattr(s, "reset_accumulators"):
            s.reset_accumulators()

        return s

    except Exception:
        raise


# ======================== FUNCIÓN initialize_hardware MEJORADA ========================
###################################
# initialize_hardware
# Argumentos: Ninguno
# Return: bool - True si inicialización exitosa, False si falla
# Descripcion: Inicializa todo el hardware del sistema incluyendo I2C, GPIO, sensores y contadores
###################################
def initialize_hardware():
    """Inicializa todo el hardware con validación mejorada"""
    global ads, adc_channels, ina_sensors, anemometer, rain_sensor, system_start_time
    global rain_count, rain_count_total, wind_count  # ASEGURAR INICIALIZACIÓN

    # VALIDACIÓN CRÍTICA: Inicializar contadores explícitamente
    rain_count = 0
    rain_count_total = 0
    wind_count = 0

    # Cleanup previo
    try:
        if rain_sensor:
            rain_sensor.close()
        if anemometer:
            anemometer.close()
        GPIO.cleanup()
    except Exception:
        pass

    print("Inicializando hardware...")
    system_start_time = time.time()

    # Inicializar InfluxDB
    global influx_initialized
    if INFLUX_AVAILABLE:
        influx_initialized = init_influxdb()
        if influx_initialized:
            print("✓ InfluxDB inicializado")
        else:
            print("⚠ InfluxDB no pudo inicializarse - solo CSV")
    else:
        influx_initialized = False

    # GPIO Setup para MUX
    try:
        GPIO.setup([MUX_S0, MUX_S1, MUX_S2], GPIO.OUT)
        print("GPIO para MUX configurado correctamente")
    except Exception as e:
        print(f"Error configurando GPIO para MUX: {e}")
        return False

    # I2C Setup
    try:
        i2c = busio.I2C(board.SCL, board.SDA)
        print("Bus I2C inicializado")
    except Exception as e:
        print(f"Error inicializando I2C: {e}")
        return False

    # ADS1115 Setup con reintentos
    for attempt in range(MAX_RETRY_ATTEMPTS):
        try:
            ads = ADS.ADS1115(i2c, address=0x48)
            ads.gain = 1
            adc_channels = [
                AnalogIn(ads, ADS.P3),  # A3 -> Z1 (MUX1)
                AnalogIn(ads, ADS.P2),  # A2 -> Z2 (MUX2)
                AnalogIn(ads, ADS.P1),  # A1 -> Z3 (MUX3)
                AnalogIn(ads, ADS.P0),  # A0 -> Direccion del viento
            ]
            print("ADS1115 inicializado correctamente")
            break
        except Exception as e:
            print(
                f"Intento {attempt + 1}/{MAX_RETRY_ATTEMPTS} - Error inicializando ADS1115: {e}"
            )
            if attempt == MAX_RETRY_ATTEMPTS - 1:
                print("No se pudo inicializar ADS1115 después de varios intentos")
                return False
            time.sleep(HARDWARE_RETRY_DELAY)

    # INA228 Setup mejorado
    print("Inicializando sensores INA228...")
    ina_sensors = {}

    for address in INA228_ADDRESSES:
        try:
            sensor = setup_ina228(i2c, address)
            ina_sensors[address] = sensor
            print(f"✓ INA228 @ 0x{address:02X} listo")
        except Exception as e:
            print(f"⚠  No se pudo inicializar INA228 @ 0x{address:02X}: {e}")
            ina_sensors[address] = None

    # Verificar si tenemos al menos un sensor INA228
    active_ina_count = sum(1 for sensor in ina_sensors.values() if sensor is not None)
    if active_ina_count == 0:
        print("WARNING: Ningún INA228 disponible. Las mediciones de potencia serán 0.")
    else:
        print(f"✓ {active_ina_count}/{len(INA228_ADDRESSES)} sensores INA228 activos")

    # Configuración GPIOZERO con manejo de errores
    try:
        anemometer = Button(
            ANEMOMETER_PIN, pull_up=True, bounce_time=0.01  # pull-up interno
        )
        anemometer.when_pressed = wind_pulse
        anemometer.when_released = wind_pulse
        print("Anemómetro configurado correctamente con gpiozero")
    except Exception as e:
        print(f"Error configurando anemómetro: {e}")
        anemometer = None

    # Rain sensor setup mejorado
    try:
        GPIO.setup(RAIN_SENSOR_PIN, GPIO.IN, pull_up_down=GPIO.PUD_UP)
        rain_sensor = Button(RAIN_SENSOR_PIN, pull_up=True, bounce_time=0.01)
        rain_sensor.when_pressed = rain_pulse
        print("🌧️ Sensor lluvia configurado correctamente")
    except Exception as e:
        print(f"Error configurando sensor lluvia: {e}")
        rain_sensor = None

    # VALIDACIÓN FINAL: Verificar que los contadores siguen siendo números
    print(
        f"[INIT] Contadores inicializados: rain_count={rain_count}, wind_count={wind_count}"
    )

    return True


###################################
# wind_pulse
# Argumentos: Ninguno
# Return: None
# Descripcion: Callback para interrupciones del anemómetro, incrementa contador de pulsos de viento
###################################
def wind_pulse():
    global wind_count
    wind_count += 1


###################################
# rain_pulse
# Argumentos: Ninguno
# Return: None
# Descripcion: Callback para pulsos del pluviómetro, actualiza contadores de lluvia y muestra información
###################################
def rain_pulse():
    """Callback para pulsos del pluviómetro"""
    global rain_count, rain_count_total, terminal_rain_count
    rain_count += 1
    rain_count_total += 1
    terminal_rain_count += 1

    timestamp = datetime.now().strftime("%H:%M:%S")
    total_mm = rain_count_total * MM_PER_TICK
    min_rain = rain_count * MM_PER_TICK
    print(f"[{timestamp}] ⚡ LLUVIA #{rain_count_total} -> {total_mm:.3f}mm total")
    print(
        f"[{timestamp}] ⚡ LLUVIA #{terminal_rain_count} -> {min_rain:.3f}mm en un minuto"
    )


###################################
# set_mux_channel
# Argumentos: channel (int) - Canal del multiplexor (0-7)
# Return: bool - True si configuración exitosa, False si falla
# Descripcion: Configura el canal activo de los multiplexores CD74HC4051 mediante GPIO
###################################
def set_mux_channel(channel):
    try:
        GPIO.output(MUX_S0, channel & 0x01)
        GPIO.output(MUX_S1, (channel >> 1) & 0x01)
        GPIO.output(MUX_S2, (channel >> 2) & 0x01)
        time.sleep(GPIO_SETUP_DELAY)
        return True
    except Exception:
        return False


###################################
# calculate_resistance
# Argumentos: voltage (float), thermistor_id (str), vcc (float, opcional)
# Return: float - Resistencia calculada en ohms
# Descripcion: Calcula la resistencia de un termistor basado en el divisor de voltaje
###################################
def calculate_resistance(voltage, thermistor_id, vcc=VCC):
    if voltage <= 0 or voltage >= vcc:
        return float("inf")

    r_ref = THERMISTOR_REF_RESISTANCES.get(thermistor_id, 10000)
    return r_ref * voltage / (vcc - voltage)


###################################
# calculate_temperature
# Argumentos: resistance (float), thermistor_id (str)
# Return: float - Temperatura en grados Celsius
# Descripcion: Convierte resistencia de termistor a temperatura usando ecuación de Steinhart-Hart simplificada
###################################
def calculate_temperature(resistance, thermistor_id):
    if resistance <= 0:
        return float("nan")

    R0 = THERMISTOR_REF_RESISTANCES.get(thermistor_id, 10000.0)
    B = 3435.0
    T0 = 298.15

    T_kelvin = 1 / ((1 / T0) + (1 / B) * math.log(resistance / R0))
    return T_kelvin - 273.15


###################################
# get_wind_speed
# Argumentos: Ninguno
# Return: float o None - Velocidad del viento en m/s o None si no hay datos suficientes
# Descripcion: Calcula velocidad del viento basada en pulsos del anemómetro durante período de medición
###################################
def get_wind_speed():
    global wind_count, last_wind_measurement

    current_time = time.time()
    time_elapsed = current_time - last_wind_measurement

    if time_elapsed >= MEASUREMENT_PERIOD:
        cps = wind_count / time_elapsed
        wind_ms = cps * (KPH_PER_COUNT_PER_SEC / 3.6)
        wind_count = 0
        last_wind_measurement = current_time
        return wind_ms

    return None


###################################
# get_wind_direction_internal
# Argumentos: Ninguno
# Return: tuple (float, str) - Ángulo en grados y dirección cardinal, o (None, None) si falla
# Descripcion: Lee dirección del viento sin mutex interno, usa tabla de resistencias vs ángulos
###################################
def get_wind_direction_internal():
    if ads is None or len(adc_channels) < 4:
        return None, None

    try:
        voltage = adc_channels[3].voltage

        if voltage is None or voltage <= 0:
            return None, None

        resistance = R_REF * voltage / (3.3 - voltage)

        closest_angle = None
        smallest_error = math.inf
        for angle, res_nom in DIRECTION_TABLE.items():
            error = abs(res_nom - resistance)
            if error < smallest_error:
                smallest_error = error
                closest_angle = angle

        tolerance = 0.15
        if (
            closest_angle is not None
            and smallest_error <= DIRECTION_TABLE[closest_angle] * tolerance
        ):
            return closest_angle, COMPASS.get(closest_angle, "")
        return None, None

    except Exception:
        return None, None


###################################
# get_wind_direction
# Argumentos: Ninguno
# Return: tuple (float, str) - Ángulo en grados y dirección cardinal, o (None, None) si falla
# Descripcion: Lee dirección del viento con protección de mutex para acceso thread-safe
###################################
def get_wind_direction():
    if ads is None or len(adc_channels) < 4:
        return None, None

    with hardware_lock:
        return get_wind_direction_internal()


###################################
# read_thermistors_internal
# Argumentos: Ninguno
# Return: dict - Diccionario con temperaturas de todos los termistores {"T0": temp, ...}
# Descripcion: Lee todos los termistores (T0-T19) sin mutex interno, usa multiplexores
###################################
def read_thermistors_internal():
    temperatures = {}

    if ads is None or len(adc_channels) < 3:
        return temperatures

    try:
        # MUX1: T0-T7
        for ch in range(8):
            thermistor_id = f"T{ch}"
            if set_mux_channel(ch):
                try:
                    voltage = adc_channels[0].voltage
                    resistance = calculate_resistance(voltage, thermistor_id)
                    temp = calculate_temperature(resistance, thermistor_id)
                    temperatures[thermistor_id] = temp
                except Exception:
                    temperatures[thermistor_id] = float("nan")

        # MUX2: T8-T15
        for ch in range(8):
            thermistor_id = f"T{ch+8}"
            if set_mux_channel(ch):
                try:
                    voltage = adc_channels[1].voltage
                    resistance = calculate_resistance(voltage, thermistor_id)
                    temp = calculate_temperature(resistance, thermistor_id)
                    temperatures[thermistor_id] = temp
                except Exception:
                    temperatures[thermistor_id] = float("nan")

        # MUX3: T16-T19
        for ch in range(4):
            thermistor_id = f"T{ch+16}"
            if set_mux_channel(ch):
                try:
                    voltage = adc_channels[2].voltage
                    resistance = calculate_resistance(voltage, thermistor_id)
                    temp = calculate_temperature(resistance, thermistor_id)
                    temperatures[thermistor_id] = temp
                except Exception:
                    temperatures[thermistor_id] = float("nan")

    except Exception:
        pass

    return temperatures


###################################
# read_thermistors
# Argumentos: Ninguno
# Return: dict - Diccionario con temperaturas de todos los termistores
# Descripcion: Lee todos los termistores con protección de mutex para acceso thread-safe
###################################
def read_thermistors():
    if ads is None or len(adc_channels) < 3:
        return {}

    with hardware_lock:
        return read_thermistors_internal()
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

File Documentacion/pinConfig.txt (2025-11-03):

sda (gpio 2)
scl (gpio 3)

-------MUX------
s0 es el menos significativo
s2 es el mas significativo
s0 -> gpio17
s1 -> gpio27
s2 -> gpio22

-------SD Module-----
MOSI -> gpio 10
MISO -> gpio 9
SCLK -> gpio 11
CS   -> gpio 8

-------DHT22-------
Signal -> GPIO5

------ANEMOMETRO-----
Signal -> gpio23

------Sensor de Lluvia----
Signal -> GPIO6

------MUX1-------
alberga sensores T0 a T7, respectivamente con Y0 a Y7
La salida del mux es Z1

------MUX2------
alberga sensores T8 a T15, respectivamente con Y0 a Y7
La salida del mux es Z2

-----MUX3------
alberga sensores T16 a T19, respectivamente con Y0 a Y3
alberga sensor de irrandiancia IRR- e IRR+, respectivamente con Y4 a Y5
La salida del mux es Z3


------ADS1115 @ direccion I2C 0x48----------------
a3 -> z1
a2 -> z2
a1 -> z3
a0 -> direccion del viento




------2 INA228 @ direcciones I2C 0x40 y 0x41------

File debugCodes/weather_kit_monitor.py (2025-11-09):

#!/usr/bin/env python3
# -*- coding: utf-8 -*-

import math
import os
import signal
import sys
import threading
import time
from datetime import datetime

import adafruit_ads1x15.ads1115 as ADS
import adafruit_dht
import board
import busio
import RPi.GPIO as GPIO
from adafruit_ads1x15.analog_in import AnalogIn
from gpiozero import Button, Device
from gpiozero.pins.pigpio import PiGPIOFactory

# Configurar gpiozero para usar pigpio
Device.pin_factory = PiGPIOFactory()

# ======================== CONFIGURACIÓN GPIO ========================
# Limpiar GPIO antes de configurar
try:
    GPIO.cleanup()
except:
    pass

GPIO.setmode(GPIO.BCM)
GPIO.setwarnings(False)

# MUX Control Pins
MUX_S0 = 17  # LSB
MUX_S1 = 27
MUX_S2 = 22  # MSB

# Sensores digitales
DHT22_PIN = 5
ANEMOMETER_PIN = 23
RAIN_SENSOR_PIN = 6

# ======================== CONFIGURACIÓN SENSORES ========================
# VCC del divisor de voltaje
VCC = 3.294  # Voltaje preciso del sistema

# DHT22
dhtDevice = adafruit_dht.DHT22(board.D5, use_pulseio=False)

# Anemómetro
KPH_PER_COUNT_PER_SEC = 2.4
MEASUREMENT_PERIOD = 1.0
wind_count = 0
last_wind_measurement = time.time()

# Sensor de lluvia
MM_PER_TICK = 0.2794
rain_count = 0
rain_count_total = 0  # Acumulador total

# Direcciones del viento (datasheet)
DIRECTION_TABLE = {
    0.0: 33_000,
    22.5: 6_570,
    45.0: 8_200,
    67.5: 891,
    90.0: 1_000,
    112.5: 688,
    135.0: 2_200,
    157.5: 1_410,
    180.0: 3_900,
    202.5: 3_140,
    225.0: 16_000,
    247.5: 14_120,
    270.0: 120_000,
    292.5: 42_120,
    315.0: 64_900,
    337.5: 21_880,
}

COMPASS = {
    0.0: "N",
    22.5: "NNE",
    45.0: "NE",
    67.5: "ENE",
    90.0: "E",
    112.5: "ESE",
    135.0: "SE",
    157.5: "SSE",
    180.0: "S",
    202.5: "SSW",
    225.0: "SW",
    247.5: "WSW",
    270.0: "W",
    292.5: "WNW",
    315.0: "NW",
    337.5: "NNW",
}

# Variables globales
rain_last_state = 1
rain_poll_thread = None
ads = None
adc_channels = []
anemometer = None
rain_sensor = None
running = True
system_start_time = None


# ======================== CÓDIGOS ANSI PARA TERMINAL ESTÁTICO ========================
class TerminalControl:
    CLEAR_SCREEN = "\033[2J"
    HOME_CURSOR = "\033[H"
    HIDE_CURSOR = "\033[?25l"
    SHOW_CURSOR = "\033[?25h"

    @staticmethod
    def goto(row, col):
        return f"\033[{row};{col}H"

    @staticmethod
    def clear_line():
        return "\033[K"


# ======================== FUNCIONES AUXILIARES ========================
def signal_handler(sig, frame):
    """Maneja la señal Ctrl+C para terminar limpiamente"""
    global running
    print(TerminalControl.SHOW_CURSOR, end="")
    print(TerminalControl.CLEAR_SCREEN, end="")
    print(TerminalControl.HOME_CURSOR, end="")
    print("\nDeteniendo monitor meteorológico...")
    running = False


def wind_pulse():
    """Callback para pulsos del anemómetro"""
    global wind_count
    wind_count += 1


def rain_pulse():
    """Callback para pulsos del pluviómetro"""
    global rain_count, rain_count_total
    rain_count += 1
    rain_count_total += 1


def start_rain_polling():
    """Inicia un hilo de polling manual para el pluviómetro (1→0 = pulso)."""
    global rain_last_state, rain_poll_thread, running

    # Configurar pin con pull-up
    try:
        GPIO.setup(RAIN_SENSOR_PIN, GPIO.IN, pull_up_down=GPIO.PUD_UP)
    except Exception as e:
        print(f"Error configurando pin de lluvia para polling: {e}")
        return False

    # Leer estado inicial
    try:
        rain_last_state = GPIO.input(RAIN_SENSOR_PIN)
        print(
            f"✓ Lluvia (GPIO {RAIN_SENSOR_PIN}) listo para polling, estado inicial: {rain_last_state} ({'HIGH' if rain_last_state else 'LOW'})"
        )
    except Exception as e:
        print(f"Error leyendo estado inicial del pin de lluvia: {e}")
        return False

    def _loop():
        global rain_last_state
        while running:
            try:
                current_state = GPIO.input(RAIN_SENSOR_PIN)
                # Detecta flanco descendente (1 → 0)
                if rain_last_state == 1 and current_state == 0:
                    rain_pulse()
                    # Debounce por hardware/agua: 300 ms evita rebotes del balancín
                    time.sleep(0.3)
                rain_last_state = current_state
                time.sleep(0.01)  # 10 ms
            except Exception as e:
                # Evitar que el hilo muera silenciosamente
                print(f"[RAIN-POLL] Error: {e}")
                time.sleep(0.5)

    rain_poll_thread = threading.Thread(target=_loop, name="RainPolling", daemon=True)
    rain_poll_thread.start()
    print("✓ Hilo de polling de lluvia iniciado")
    return True
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

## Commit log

2025-11-09 Preparar repositorio para publicación en Zenodo
    - Agregar licencia MIT (solo Maickol A. Fernandez Obando)
    - Crear archivo .zenodo.json con metadatos del proyecto
    - Agregar CITATION.cff para citación estándar
    - Configurar .gitignore para excluir archivos innecesarios
    - Configurar herramientas de linting (black, isort, flake8)
    - Actualizar README con badges y sección de citación
    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
2025-11-09 Arreglar .zenodo.json para compatibilidad con Zenodo
    - Remover campos related_identifiers con placeholder inválido
    - Simplificar metadatos para evitar errores de validación
2025-11-09 Actualizar DOI de Zenodo en README y CITATION.cff
    - Agregar DOI real: 10.5281/zenodo.17563420
    - Actualizar badges en README
    - Actualizar cita BibTeX con versión v1.0.1
    - Actualizar CITATION.cff con DOI y URL de Zenodo
2025-11-15 Change thermistor readings deque maxlen to 12
2025-12-05 Security: Remove hardcoded credentials and add environment variable support
    - Replace InfluxDB credentials with environment variables
    - Add .env.example and CONFIGURACION.md for setup
    - Document InfluxService functions and add README
    - Fix code quality issues (flake8, black, isort)
    [implementacion.py, influxdb_sender.py]

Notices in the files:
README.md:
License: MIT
